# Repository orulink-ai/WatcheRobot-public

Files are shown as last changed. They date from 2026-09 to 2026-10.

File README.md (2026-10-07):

English | [简体中文](README_zh.md)

# WatcheRobot

The public WatcheRobot desktop-robot repository provides hardware files, mechanical models, the Python SDK, flashing tools, user guides, and Release asset documentation.

## Project Preview

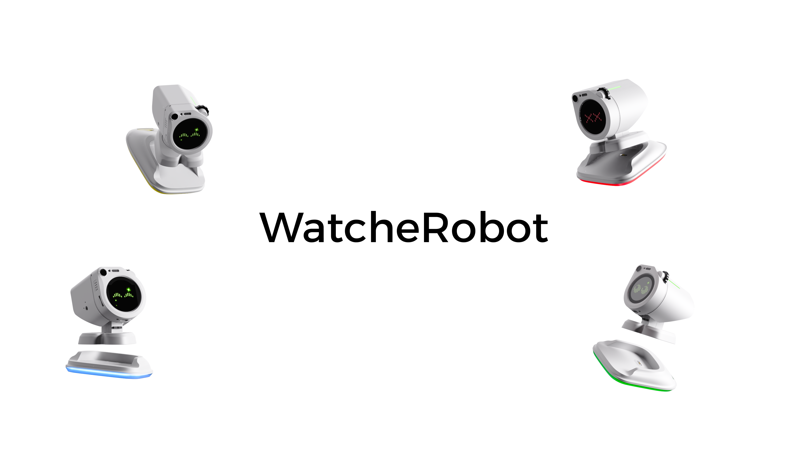
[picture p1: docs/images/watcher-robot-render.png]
WatcheRobot desktop robot


WatcheRobot is designed for desktop companionship, interactive demos, and developer experiments. It combines a Watcher head, ESP32-S3, an STM32 body board, servos, mechanical parts, and SD-card resources. You can use it through Desktop, the mobile App, or the Python SDK.

## Quick Start

### 1. Get the Repository

```bash
git clone --recurse-submodules https://github.com/orulink-ai/WatcheRobot-public.git
cd WatcheRobot-public
```

If `python-sdk/` is empty in an existing clone, run:

```bash
git submodule update --init --recursive
```

### 2. Prepare the Environment and Materials

See the [OSHW project](https://oshwhub.com/team_efhmhuqf/project_gbxcghnl) for the bill of materials and assembly steps.

| Prepare | Purpose |
| --- | --- |
| Assembled Watcher head and robot body | Flash and run the robot |
| ST-LINK V2 | Flash STM32 on the body board |
| USB data cable | Flash Himax and ESP32-S3 in the head |
| SD card and card reader | FAT32, 512-byte allocation unit; write expression, movement, and other resources |
| Conda | Create an isolated environment; the scripts prepare the remaining dependencies and tools |
| Computer or phone | Use Desktop, App, or SDK |

### 3. Prepare the Robot

Open the [Flashing Guide](docs/flashing.md) and follow its sections in order:

1. Flash STM32 on the body board.
2. Fully flash the Watcher head; the script writes Himax first and initializes ESP32-S3 from the release package.
3. Use a card reader and the repository writer to install the SD resources, then return the card to the head.
4. Power on, open Phone Control, connect the phone, then check one expression and one small movement.

### 4. Connect and Use

Download the required client or SDK from the [Latest Release](https://github.com/orulink-ai/WatcheRobot-public/releases/latest):

| Interface | Download |
| --- | --- |
| Windows Desktop | x64 `.exe` installer |
| macOS Desktop | Apple Silicon `.dmg` installer |
| Android App | `.apk` installer |
| iOS App | [TestFlight](https://testflight.apple.com/join/XFCFsm5M) |
| Python SDK | `watcherobot` `.whl`; follow the [SDK Guide](docs/sdk.md) |

See the [device network setup guide (Chinese PDF)](docs/manuals/device-network-setup.pdf). Once connected, run one expression and one movement to check the display, lights, and motion.

## Build Your Own Embedded Firmware (Development Preview, Not Publicly Released)

Alongside the [Python SDK](docs/sdk.md) for host applications, we are preparing
an independent ESP32-S3 hardware SDK. Developers own their `app_main`, UI, and
application logic, using a unified interface for body motion, lights, body touch,
camera, microphone, speaker, display, and screen touch. It does not require the
official application, Python SDK, Daemon, or server.

The first release targets three independently buildable examples: body, head,
and whole robot. STM32 and Himax use a validated firmware pairing; developers
are not expected to modify their firmware. See the
[Embedded Development Preview](docs/embedded-sdk.md) for scope and release gates.

Source and three examples are in [firmware/sdk/](firmware/sdk/README.md), currently
a development preview without full hardware acceptance or a pinned release.
Existing Releases and tools flash official firmware, not everyday custom builds.
Official application and STM32/Himax implementations remain outside SDK open-source scope.

## Repository Structure

```text
WatcheRobot-public/
├─ README.md / README_zh.md       English and Chinese project entry
├─ docs/
│  ├─ flashing.md / flashing_zh.md        Flashing guide
│  ├─ sd-card-assets.md / sd-card-assets_zh.md    SD-card resource guide
│  ├─ action-test.md / action-test_zh.md          First-run check
│  ├─ sdk.md / sdk_zh.md                  SDK guide
│  ├─ embedded-sdk.md / embedded-sdk_zh.md Embedded SDK preview and release boundaries
│  ├─ versions.md / versions_zh.md        Version sources
│  ├─ compatibility.md / compatibility_zh.md      Compatibility notes
│  ├─ release-process.md / release-process_zh.md  Release rules
│  ├─ governance.md / governance_zh.md            Repository rules
│  ├─ images/                              Documentation images
│  └─ manuals/                             PDF user manuals
├─ firmware/README.md / README_zh.md       Firmware download entry
├─ hardware/
│  ├─ pcb/
│  │  ├─ schematic/                        Schematics
│  │  ├─ layout/                           PCB layouts
│  │  ├─ gerber/                           Production files
│  │  ├─ bom/ / cpl/                      BOM and placement files
│  │  └─ pcb-source/                       EasyEDA Pro project source
│  └─ 3d-models/exports/                   STEP mechanical models
├─ python-sdk/                             Python SDK submodule
├─ skills/watche-release-flash/
│  ├─ SKILL.md                             English flashing Skill
│  └─ SKILL_zh.md                          Chinese flashing Skill
├─ skills/watche-sd-card-write/
│  ├─ SKILL.md                             English SD-card Skill
│  └─ SKILL_zh.md                          Chinese SD-card Skill
├─ tools/
│  ├─ flash.ps1                            Windows flashing entry
│  ├─ flash.sh                             macOS/Linux flashing entry
│  ├─ flash_setup.py                       Dependency setup and flashing dispatcher
│  ├─ install_sd_card_resources.py         SD validation and writer
│  └─ sd_package.py                        Official SD package resolver
├─ .github/                                Issue, PR, and CI configuration
├─ CONTRIBUTING.md / CONTRIBUTING_zh.md    Contribution guide
├─ SECURITY.md / SECURITY_zh.md            Security policy
└─ LICENSE                                 Open-source license
```

## Project Documentation

- [Flashing Guide](docs/flashing.md): environment, wiring, firmware flashing, SD card, and startup checks.
- [Firmware Entry Point](firmware/README.md): download package and flashing entry for each target.
- [SD-card Resources](docs/sd-card-assets.md) and [First-run Check](docs/action-test.md).
- [SDK Guide](docs/sdk.md): installation, pairing, and running Python scripts.
- [Embedded Development Preview](docs/embedded-sdk.md): hardware SDK goals, examples, and current release status.
- [Hardware Files](hardware/README.md): PCB and mechanical-file entry point.
- [Full User Manual (Chinese PDF)](docs/manuals/WatcheRobot-user-manual-20260724.pdf).
- [Version Sources](docs/versions.md), [Compatibility](docs/compatibility.md), [Release Rules](docs/release-process.md), and [Repository Rules](docs/governance.md).
- [Contributing Guide](CONTRIBUTING.md) and [Security Policy](SECURITY.md).

## Open-source Scope

- This repository publishes hardware production files, mechanical models, the Python SDK, flashing tools, and documentation.
- Python SDK source is provided through the `python-sdk/` submodule.
- ESP32-S3, Himax, STM32, App, server, and Desktop source code is not published here.
- Firmware, client installers, and SD-card resources are distributed through GitHub Releases.

## Technology Stack

| Area | Technology or format |
| --- | --- |
| Head | Watcher, Himax, ESP32-S3 |
| Body control | STM32F103, SWD / ST-LINK |
| SDK and flashing tools | Python, PowerShell, Bash |
| Hardware files | Schematic, PCB, BOM, CPL, Gerber, STEP |

## License

This repository uses [GPL-3.0](LICENSE). Subprojects and third-party components retain their own licenses.

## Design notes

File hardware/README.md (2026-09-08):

<p><strong>English</strong> | <a href="README_zh.md">简体中文</a></p>

# Hardware Package

This directory contains the public hardware reproduction materials for WatcheRobot.

For the public hardware project and material entry, see the [WatcheRobot OSHW project](https://oshwhub.com/team_efhmhuqf/project_gbxcghnl). Complete assembly and power-off wiring checks before firmware flashing.

## Package Map

| Board or asset | Schematic | Layout | Gerber | BOM | CPL | Source |
| --- | --- | --- | --- | --- | --- | --- |
| Feedback servo STM32 co-processor board | `pcb/schematic/SCH_STM32Servo_反馈舵机控制板.pdf` | `pcb/layout/PCB_STM32Servo_反馈舵机控制板.pdf` | `pcb/gerber/Gerber_STM32Servo_反馈舵机控制板/` | `pcb/bom/BOM_STM32Servo_反馈舵机控制板.xlsx` | `pcb/cpl/CPL_STM32Servo_反馈舵机控制板.xlsx` | `pcb/pcb-source/ProPrj_WatcheRobot2.0openSource_2026-06-17.epro` |
| Foot charging board | `pcb/schematic/SCH_FootCharger_脚底充电板.pdf` | `pcb/layout/PCB_FootCharger_脚底充电板.pdf` | `pcb/gerber/Gerber_FootCharger_脚底充电板/` | `pcb/bom/BOM_FootCharger_脚底充电板.xlsx` | `pcb/cpl/CPL_FootCharger_脚底充电板.xlsx` | `pcb/pcb-source/ProPrj_WatcheRobot2.0openSource_2026-06-17.epro` |
| Wireless charging base | `pcb/schematic/SCH_WirelessBase_无线充电底座.pdf` | `pcb/layout/PCB_WirelessBase_无线充电底座.pdf` | `pcb/gerber/Gerber_WirelessBase_无线充电底座/` | `pcb/bom/BOM_WirelessBase_无线充电底座.xlsx` | `pcb/cpl/CPL_WirelessBase_无线充电底座.xlsx` | `pcb/pcb-source/ProPrj_WatcheRobot2.0openSource_2026-06-17.epro` |
| Side LED board | `pcb/schematic/SCH_SideLight_侧边灯板.pdf` | `pcb/layout/PCB_SideLight_侧边灯板.pdf` | `pcb/gerber/Gerber_SideLight_侧边灯板/` | `pcb/bom/BOM_SideLight_侧边灯板.xlsx` | `pcb/cpl/CPL_SideLight_侧边灯板.xlsx` | `pcb/pcb-source/ProPrj_WatcheRobot2.0openSource_2026-06-17.epro` |
| Mechanical assembly | - | - | - | - | - | `3d-models/exports/WatcherRobot-mian.stp` |

## BOM Notes

The current BOM workbooks include:

- designator
- quantity
- parameter or model
- component description
- footprint
- manufacturer or brand
- manufacturer part number
- LCSC number
- supplier
- supplier part number
- datasheet
- mounting method
- alternate part

Purchase URLs and spare quantities are not fully populated in the current BOM files. Use `pcb/spares.md` to track spare parts and links.

## Large File Note

`3d-models/exports/WatcherRobot-mian.stp` is the current public mechanical assembly model. Future larger mechanical exports should be published through GitHub Releases or Git LFS rather than normal Git history.

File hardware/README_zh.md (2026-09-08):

<p><a href="README.md">English</a> | <strong>简体中文</strong></p>

# 硬件资料

物料和装配步骤见[立创开源硬件项目](https://oshwhub.com/team_efhmhuqf/project_gbxcghnl)。本目录保存 PCB、BOM、贴片坐标、Gerber 和机械模型。

| 实物 | 资料位置 |
| --- | --- |
| 身体主板，也就是反馈舵机 STM32 控制板 | `pcb/` 中名称包含 `STM32Servo` 的文件 |
| 脚底充电板 | `pcb/` 中名称包含 `FootCharger` 的文件 |
| 无线充电底座 | `pcb/` 中名称包含 `WirelessBase` 的文件 |
| 侧边灯板 | `pcb/` 中名称包含 `SideLight` 的文件 |
| 机械结构 | `3d-models/exports/WatcherRobot-mian.stp` |

先完成装配并断电检查接线，再开始烧录。身体主板使用 ST-LINK/SWD 烧录 STM32；上方 Watcher 头部通过 USB 烧录 Himax 和 ESP32-S3。

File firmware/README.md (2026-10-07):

English | [简体中文](README_zh.md)

# Firmware Entry Point

Independent ESP32 hardware SDK source and examples are provided in [sdk/](sdk/README.md) as a development preview. Official ESP32 application, Himax and STM32 implementations remain unpublished. Official flashable firmware is distributed through the [Latest Release](https://github.com/orulink-ai/WatcheRobot-public/releases/latest).

| Target | Download from the Release | Method |
| --- | --- | --- |
| STM32 body board | STM32 firmware package | Connect ST-LINK V2 to the body board and run the repository script |
| Watcher head | Paired Himax + ESP32-S3 package | Connect the head by USB and follow the guide for the initial full flash |
| SD card | SD resource archive | Install it with a card reader and the repository writer |

See the [Flashing Guide](../docs/flashing.md) for environment, wiring, and commands; [SD-card Resources](../docs/sd-card-assets.md) for card contents; and the [First-run Check](../docs/action-test.md) after startup.

Codex users can also ask the assistant to read [`skills/watche-release-flash/SKILL.md`](../skills/watche-release-flash/SKILL.md) and follow it for flashing.

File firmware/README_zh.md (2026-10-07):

[English](README.md) | 简体中文

# 固件入口

本仓库在 [sdk/](sdk/README_zh.md) 提供 ESP32 独立硬件 SDK 源码与示例（开发预览）。官方 ESP32 应用、Himax 和 STM32 固件实现仍不公开。官方可烧录固件由 [Latest Release](https://github.com/orulink-ai/WatcheRobot-public/releases/latest) 提供。

| 目标 | Release 中下载什么 | 使用方式 |
| --- | --- | --- |
| 身体主板 STM32 | STM32 固件包 | ST-LINK V2 连接身体主板，运行仓库烧录脚本 |
| Watcher 头部 | Himax + ESP32-S3 配套包 | USB 连接头部，首次安装按指南执行完整烧录 |
| SD 卡 | SD 资源压缩包 | 用读卡器和仓库写卡脚本安装 |

环境、接线和命令见[烧录指南](../docs/flashing_zh.md)，SD 卡内容见[SD 卡资源说明](../docs/sd-card-assets_zh.md)，开机后按[首次运行检查](../docs/action-test_zh.md)确认设备。

Codex 用户也可以让助手读取 [`skills/watche-release-flash/SKILL_zh.md`](../skills/watche-release-flash/SKILL_zh.md)，再按提示执行烧录。

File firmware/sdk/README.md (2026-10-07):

English | [简体中文](README_zh.md)

# ESP32 Embedded Hardware SDK (Development Preview)

This directory contains `watche_hw_*` source, required drivers and three independent
ESP-IDF projects. Developers own `app_main`, without the official app, Python SDK,
Daemon, server, SD card or models. Full hardware acceptance is pending; this is not
a stable release.

## Getting started

1. Download this repository or run `git clone https://github.com/orulink-ai/WatcheRobot-public.git`.
2. Install ESP-IDF **6.0.2** with ESP32-S3 tools and activate its terminal environment.
3. Edit `firmware/sdk/examples/robot/main/app_main.c`: this is your application.
4. From the repository root run `idf.py -C firmware/sdk/examples/robot build`.
5. Verify the port and paired firmware, back up required data, then run
   `idf.py -C firmware/sdk/examples/robot -p <PORT> flash monitor`.

Replace `<PORT>` with the actual serial port. Target: ESP32-S3, 16MB flash and
octal PSRAM for head examples. A successful build is not hardware safety evidence.
Long presses in body examples may trigger small movements; clear the mechanism first.

## Examples and modules

- `examples/body`: motion, lights, body touch. No motion without fresh valid position feedback.
- `examples/head`: LVGL and screen touch, JPEG capture, short PCM recording/playback.
- `examples/robot`: combined application; recommended starting point.
- `components/sdk/watche_hw_*`: public headers; other components are required dependencies.

Examples own their CMake, partitions and configuration. They never include the
official application project. Headers document parameters, ownership and threading.
Generic ACK/NACK are motion events only when matching the motion service's last
32 command sequences; older replies are ignored. Typed DONE/FAULT retain their
original sequence. Body init/close during event dispatch returns
`ESP_ERR_INVALID_STATE`; close only after dispatch returns.
Applications dispatch body callbacks with `dispatch_events`; submission is not motion
completion. Commands are rejected before readiness; reconnection never replays motion.
JPEG bytes are borrowed during callbacks; copy to retain. Blocking audio belongs in
application tasks. Lock LVGL access; never record or close display while holding its lock.

## Using a separate project

Keep a pinned checkout of this repository beside your project. In your top-level
CMake, set `HW_BODY` / `HW_HEAD` and include this SDKs `examples/sdk.cmake` before
`project()`, then call `watche_hw_check_idf()`. It finds components relative to itself,
not a private repository. Declare selected `watche_hw_*` main-component dependencies
and reuse the matching example manifest, partitions and sdkconfig.defaults.
Disable `HW_HEAD` for body-only projects. Do not ship products against floating main.

## Scripts and flashing

Windows: `./firmware/sdk/examples/hardware-sdk.ps1 robot build`.
macOS/Linux: `bash firmware/sdk/examples/hardware-sdk.sh robot build`.
Both accept example (default robot), action (default build), port. Actions are
build/flash/monitor; flash and monitor require an explicit port.

See the [official flashing guide](../../docs/flashing.md) for initial STM32/Himax
preparation and restoring official firmware. Official tools replace custom ESP32
applications; do not use them for everyday SDK flashing. Camera requires paired
PTL Himax firmware; current Releases are not guaranteed to contain it. Do not flash
unknown pairs before checking [acceptance](VALIDATION.md). First flash writes the
bootloader and partition table and may overwrite storage; do not erase flash.
Use `app-flash` for later application updates only after confirming unchanged partitions
on the connected device, not only in the local build. If the device's layout is
unknown or another firmware was installed, use this example's complete `flash`.

The body runtime probes a quiet peer using control-plane HELLO frames; no
periodic sensor stream or servo-position query is required for liveness. Five
seconds without a valid protocol event invalidates readiness and starts recovery.
Disconnect safety depends on STM32 mechanisms, not guaranteed ESP32 stop delivery.

## Licensing and maintenance

First-party source in this directory retains the upstream ESP32 [Apache-2.0](LICENSE)
license; the repository-root GPL-3.0 does not replace it. Seeed BSP, SSCMA, expander
and Espressif codec directories retain original licenses and copyright notices.
Registry dependencies keep their respective licenses. This is a public delivery
snapshot; the internal ESP32 repository remains the development source. Fixes must
flow back upstream, not create an independently maintained duplicate. Official
application and STM32/Himax implementations remain outside this publication scope.

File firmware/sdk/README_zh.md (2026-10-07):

[English](README.md) | 简体中文

# ESP32 嵌入式硬件 SDK（开发预览）

这里提供 `watche_hw_*` 源码、必要驱动和三个独立 ESP-IDF 工程。
开发者拥有自己的 `app_main`，不需要官方应用、Python SDK、Daemon、服务端、
SD 卡或模型。尚未完成全部实机验收，不是稳定版发布。

## 小白从这里开始

1. 下载本仓库，或执行 `git clone https://github.com/orulink-ai/WatcheRobot-public.git`。
2. 安装 ESP-IDF **6.0.2** 和 ESP32-S3 工具链，在 ESP-IDF 终端执行后续命令。
3. 打开 `firmware/sdk/examples/robot/main/app_main.c`，这是你自己的应用。
4. 在仓库根目录执行 `idf.py -C firmware/sdk/examples/robot build`。
5. 确认设备端口和配套固件，备份需要的数据，再执行
   `idf.py -C firmware/sdk/examples/robot -p <PORT> flash monitor`。

`<PORT>` 替换为实际串口名称，不要原样输入。工程目标为 ESP32-S3、16MB Flash，
头部示例启用 octal PSRAM。构建不等于实机安全验收。身体示例长按可能触发小幅运动，
首次操作前保持机构运动空间畅通。

## 示例与模块

- `examples/body`：运动、灯光、身体触摸。未收到新鲜有效位置反馈不运动。
- `examples/head`：LVGL 页面和屏幕触摸、JPEG 拍照、短时 PCM 录放音。
- `examples/robot`：上述能力组合，建议作为开发起点。
- `components/sdk/watche_hw_*`：公共接口；`components` 其余目录是必要底层依赖。

全部示例有自己的 CMake、分区和配置，不引入官方固件顶层工程。
公共头文件说明参数、所有权和线程限制。身体回调由应用调用 `dispatch_events`
分发，运动提交成功不是运动完成；未就绪拒绝控制，重连不重放动作。
通用 ACK/NACK 仅在匹配运动服务最近 32 个命令时报告为运动事件，超出窗口的
迟到回复忽略；带类型的完成/故障保留原始序列。事件分发期间 init/close 返回
`ESP_ERR_INVALID_STATE`，应用应在分发返回后再关闭。
身体运行层在通信安静时发送 HELLO 存活探测，不要求 STM32 周期上报传感器，
也不查询舵机位置。超过 5 秒未收到有效协议事件会退出就绪并重新握手。
摄像头回调 JPEG 只在回调内有效，需保存则复制；音频阻塞操作放应用任务；
LVGL 操作使用显示锁，不能在持锁时录音或关闭显示。

## 在自己的新工程中使用

将本仓库的固定版本作为依赖保留在项目旁边。自己的顶层 CMake 在
`project()` 前设置 `HW_BODY` / `HW_HEAD`，并 include 本 SDK 的
`examples/sdk.cmake`；它使用自己的位置寻找组件，不依赖私有仓库。
在 `project()` 后调用 `watche_hw_check_idf()`。主组件声明实际使用的
`watche_hw_*` 依赖，并沿用相应示例的依赖清单、分区和 sdkconfig.defaults。
只需身体时关闭 `HW_HEAD`，不会初始化头部。不要依赖浮动 main 发布产品。

## 脚本与烧录边界

Windows：`./firmware/sdk/examples/hardware-sdk.ps1 robot build`。
macOS/Linux：`bash firmware/sdk/examples/hardware-sdk.sh robot build`。
两个入口的参数都是：示例（默认 robot）、操作（默认 build）、端口。
操作支持 build/flash/monitor；flash 和 monitor 必须显式指定端口。

首次准备 STM32/Himax 和恢复官方整机见[官方烧录指南](../../docs/flashing_zh.md)。
现有官方工具会替换自定义 ESP32 应用，不要用于日常 SDK 烧录。
SDK 摄像头需要 PTL 配对 Himax；现有 Release 不保证包含该配对，
未经[兼容验收](VALIDATION.md)确认不要直接刷写未知镜像。
自定义首次 flash 会写 bootloader 和分区表，可能覆盖存储；不要执行 erase-flash。
确认连接设备上的分区不变后日常可用 `app-flash`，不能只检查本地构建配置。
设备布局未知或曾安装另一份固件时，使用本示例的完整 `flash`。
断线停止依赖 STM32 安全机制，
不能承诺断线后 ESP32 还能发送停止命令。

## 许可证与维护

本目录自有代码沿用内部 ESP32 源码的 [Apache-2.0](LICENSE)，
不以公开仓库根目录 GPL-3.0 替代原许可。Seeed BSP、SSCMA、I/O expander
和 Espressif codec 等保留各目录原有许可证与版权；注册表依赖也适用其各自许可。
本目录是 SDK 的对外交付快照，开发源仍在内部 ESP32 仓库；对外修复应回流开发源，
不能维护两套独立实现。官方应用、STM32/Himax 实现不在本目录公开范围内。

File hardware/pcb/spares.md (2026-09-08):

<p><strong>English</strong> | <a href="spares_zh.md">简体中文</a></p>

# Event Spare Parts

Use this file to track spare parts prepared for reproduction or maintenance. The BOM workbooks contain model, supplier, supplier part number, and alternate-part fields; this document records what is physically available on site.

## Spare Parts Template

| Board | Part or designator | Recommended spare qty | Supplier link | Alternate part | Event location | Notes |
| --- | --- | ---: | --- | --- | --- | --- |
| Feedback servo STM32 co-processor board | TBD | TBD | TBD | TBD | TBD | Fill before release. |
| Foot charging board | TBD | TBD | TBD | TBD | TBD | Fill before release. |
| Wireless charging base | TBD | TBD | TBD | TBD | TBD | Fill before release. |
| Side LED board | TBD | TBD | TBD | TBD | TBD | Fill before release. |

## Minimum Event Checklist

- Confirm every spare item maps to a BOM row.
- Add a purchase or supplier link where possible.
- Mark spare parts that are prepared but not normally assembled.
- Keep the physical storage location clear enough for builders and maintainers.
- Update this file before publishing a full hardware release.

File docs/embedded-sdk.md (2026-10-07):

English | [简体中文](embedded-sdk_zh.md)

# Independent Embedded Hardware SDK: Development Preview

## Current Status

This document describes direction and interface boundaries. Development-preview
source, independent examples and build instructions are in
[firmware/sdk](../firmware/sdk/README.md). There is no stable release or complete
hardware-validated STM32/Himax pairing yet; do not treat the preview as stable.

The available development entry remains the [Python SDK](sdk.md). Existing
firmware and client assets are listed in
[Releases](https://github.com/orulink-ai/WatcheRobot-public/releases).

## Two Development Paths

| Path | Runs on | Developer ownership | Status |
| --- | --- | --- | --- |
| Python SDK | Host computer | Applications using existing device firmware | Public entry available; see the SDK guide |
| Embedded hardware SDK | ESP32-S3 | Own app_main, UI, interactions, and hardware calls | Development preview; not publicly released |

The embedded SDK aims to run independently of the official application, without
the Python SDK, Daemon, or server. It does not change the existing
Python SDK/Daemon/Application architecture.

## First-release Target Capabilities

| Module | Target interfaces |
| --- | --- |
| Body motion | Target angles in degrees, duration, stop; completion, rejection, and fault events |
| Body lights | Zone colors, brightness, and basic effects |
| Body touch | Ordered press, release, and long-press events |
| Camera | PTL backend; single capture, continuous JPEG frames, stop, and status |
| Microphone and speaker | PCM capture, playback, volume, and format configuration |
| Display and screen touch | Standard LCD/LVGL/touch handles and access protection |

Modules are optional components named `watche_hw_*`; developers own application
behavior. Voice assistants, cloud connections, official expressions, AI inference,
and model management are outside the first release. The target toolchain is
ESP-IDF **6.0.2** and ESP32-S3, with required dependencies pinned.

The runtime owns MCU handshaking, event collection, state transitions, and disconnect
handling. Applications subscribe to events. Successful motion submission does not
mean completion; commands must be rejected before readiness, and reconnects must
not replay old motion. Callbacks handle lightweight events; expensive work belongs
in application tasks. Published SDK documentation must specify resource contracts,
including JPEG buffer lifetime and display locking.

## Independent Example Targets

- Body: touch changes lights, user-triggered small motion, completion/fault logging.
- Head: simple LVGL page, screen touch, JPEG capture, short PCM recording/playback.
- Whole robot: combine these capabilities and demonstrate resource ownership.

Basic examples require neither an SD card nor model resources. Developers edit
example application code without starting the official top-level firmware project
or modifying STM32/Himax firmware.

## Flashing and Safety Boundaries

The final delivery must distinguish first-time STM32/Himax preparation, everyday
custom ESP32 flashing, and restoration of official whole-robot firmware.

The current [Flashing Guide](flashing.md) covers official firmware. Existing tools
may write the official ESP32 application and must not be used to preserve a custom
application. Custom partition layouts may overwrite storage; the released guide
must document backup and restoration. Until the independent development entry is
released, this preview provides no unverified custom flashing commands.

After disconnection, ESP32 cannot guarantee delivery of a stop command; safety
depends on STM32-side mechanisms. Motion examples require limit, small-movement,
and stop validation. A successful build is not evidence of motion safety.

## Public Release Gates

- Confirm public source delivery, licensing, and a fixed Git revision; update
  the published open-source scope accordingly.
- Validate installation, all three builds, and application-only edits from a clean checkout.
- Run Windows/Linux host tests and pinned-IDF CI, including official firmware regression.
- Validate motion, lights, all three body-touch events, JPEG decoding, PCM recording/
  playback, screen touch, and combined operation on hardware. Missing or incompatible
  modules must not hang the device or unintentionally drive motors.
- Record SDK/STM32 versions, Himax image checksum, board revision, and acceptance evidence.
- Validate custom flashing and official restoration, with equivalent PowerShell/Shell entries.

Do not release version one until both head and body pass acceptance. This document
does not promise a release date.

[Back to the project](../README.md)

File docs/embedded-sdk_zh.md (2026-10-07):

[English](embedded-sdk.md) | 简体中文

# 独立嵌入式硬件 SDK：开发预览

## 当前状态

这是一份开发方向和接口边界说明。开发预览源码、独立示例及构建入口见
[firmware/sdk](../firmware/sdk/README_zh.md)。尚无稳定发布版本和完整实机
STM32/Himax 配对验收；请勿将预览当作稳定版。

目前可用的开发入口仍是 [Python SDK](sdk_zh.md)。固件和客户端的已有发行
资产见 [Release](https://github.com/orulink-ai/WatcheRobot-public/releases)。

## 两种开发方式

| 方式 | 运行位置 | 开发者控制的内容 | 状态 |
| --- | --- | --- | --- |
| Python SDK | 电脑端 | 基于已有设备固件编写应用 | 已有公开入口，见 SDK 指南 |
| 嵌入式硬件 SDK | ESP32-S3 | 自己的 app_main、UI、交互及硬件调用 | 源码开发预览，尚未正式发布 |

嵌入式 SDK 的目标是脱离官方应用运行，不要求 Python SDK、Daemon 或服务端。
它不改变现有 Python SDK/Daemon/Application 架构。

## 首版目标能力

| 模块 | 目标接口 |
| --- | --- |
| 身体运动 | 目标角度（度）、运动时间、停止；完成、拒绝、故障事件 |
| 身体灯光 | 分区颜色、亮度和基础灯效 |
| 身体触摸 | 按下、释放、长按的有序事件流 |
| 摄像头 | PTL 后端，单次拍照、连续 JPEG 取帧、停止与状态 |
| 麦克风与扬声器 | PCM 采集、播放、音量与格式配置 |
| 屏幕与屏幕触摸 | 标准 LCD/LVGL/触摸句柄及访问保护 |

组件按模块可选，统一使用 `watche_hw_*` 命名；开发者编写自己的业务。
首版不包含语音助手、云连接、官方表情系统、AI 推理和模型管理。
目标工具链为 ESP-IDF **6.0.2**、ESP32-S3，必要依赖固定版本。

运行层负责 MCU 握手、事件采集、状态转换和断线处理；应用通过订阅接收
事件。运动提交成功不等于运动完成，未就绪应拒绝控制，重连不重放旧运动。
回调只处理轻量事件，耗时业务放到应用任务；JPEG 缓冲生命周期和显示锁
等资源合同必须在正式 SDK 文档中明确。

## 独立示例目标

- 身体：触摸改变灯光，用户触发小幅运动，打印完成或故障事件。
- 头部：简单 LVGL 页面、屏幕触摸、JPEG 拍照、短时 PCM 录音与回放。
- 整机：组合上述能力，展示模块共同运行和资源所有权。

基础示例不依赖 SD 卡或模型资源。开发者只修改示例应用代码，不必启动
官方固件顶层工程，也不要求修改 STM32/Himax 固件。

## 烧录与安全边界

正式交付必须分别说明首次准备 STM32/Himax、日常只烧录自定义 ESP32、
恢复官方整机固件三个流程。

当前 [烧录指南](flashing_zh.md)描述的是官方整机流程；现有工具可能写入
官方 ESP32 应用，不能用于保留自定义应用。自定义工程也可能改变分区并
覆盖存储。预览的构建与自定义烧录入口见 [SDK 入门说明](../firmware/sdk/README_zh.md)，
操作前请阅读其中的备份要求和配对固件限制；稳定版仍需完整实机验收。

断线后不能保证 ESP32 仍能发送停止命令，安全停止依赖 STM32 侧机制。
运动示例必须经过限位、小幅运动和停止验收，不能把构建通过当作安全证明。

## 公开发布门禁

- 确认公开源码交付方式、许可证和固定 Git 版本；同步仓库开源范围说明。
- 从干净 checkout 验证工具安装、三个示例构建及仅修改应用代码的流程。
- Windows/Linux 主机测试和固定 IDF CI；回归官方固件。
- 实机验收运动、灯光、三类身体触摸、JPEG 解码、PCM 录放音、屏幕触摸
  和整机组合；缺失或不兼容模块不得挂死或无意驱动电机。
- 记录 SDK 版本、STM32 版本、Himax 镜像校验值、板卡版本和验收证据。
- 验证自定义烧录与官方恢复流程，并提供语义一致的 PowerShell/Shell 入口。

头部和身体全部通过前不发布首版；本文不承诺发布日期。

[返回项目入口](../README_zh.md)

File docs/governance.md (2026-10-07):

<p><strong>English</strong> | <a href="governance_zh.md">简体中文</a></p>

# Governance

`orulink-ai/WatcheRobot-public` is the public repository for hardware materials, mechanical models, SDK source, user documentation, flashing tools, and release coordination.

Maintainers should keep the following boundaries clear:

- Python SDK source is provided through the `python-sdk/` submodule.
- Hardware source changes belong under `hardware/pcb/`, `hardware/3d-models/`, or `hardware/assembly/`.
- `firmware/sdk/` publishes the independent ESP32 hardware SDK, required drivers and examples, retaining Apache-2.0 and original third-party licenses.
- Official ESP32 application, STM32F103 and Himax implementations are not published in this repository.
- App, server, desktop, firmware, and SD-card runtime artifacts are release assets only.
- Release artifacts are uploaded to GitHub Releases, not committed to Git.
- Private implementation details do not belong in public docs.

Branch protection should require CI and owner review before public release.

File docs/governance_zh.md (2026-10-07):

<p><a href="governance.md">English</a> | <strong>简体中文</strong></p>

# 仓库规则

- Python SDK 使用 `python-sdk/` 子模块。
- 硬件资料放在 `hardware/`。
- `firmware/sdk/` 公开独立 ESP32 硬件 SDK、必要驱动和示例；保留该目录 Apache-2.0 与第三方原有许可证。
- 官方 ESP32 应用、STM32F103、Himax、App、服务端和桌面端实现不放入本仓库。
- 固件、客户端安装包和 SD 卡资源只上传到 GitHub Releases。
- 私有路径、账号、凭据和内部日志不得写入公开文档。

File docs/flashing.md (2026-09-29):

English | [简体中文](flashing_zh.md)

# Flashing and First Use

See the [OSHW project](https://oshwhub.com/team_efhmhuqf/project_gbxcghnl) for parts and assembly. Once hardware is ready, follow the steps below.

## 1. Prepare Materials, Files, and Environment

Have the STM32 body board, Watcher head, ST-LINK V2, USB data cable, SD card, and card reader ready. Disconnect power before changing wiring or inserting/removing the SD card.

Download and extract these assets from the [Latest Release](https://github.com/orulink-ai/WatcheRobot-public/releases/latest):

| Asset name contains | Purpose |
| --- | --- |
| STM32 | Body board firmware |
| PTL-paired | Complete head Himax and ESP32-S3 firmware and paired tools |
| sd-resources | SD-card resources; the writer can also download the latest package |

Use Conda, or install [Miniconda](https://docs.conda.io/projects/miniconda/en/latest/) first. Open a Conda-enabled terminal at the repository root (Anaconda PowerShell Prompt on Windows). Create the dedicated environment once:

```sh
conda create -n watcherobot python=3.12 pip -y
conda activate watcherobot
```

Run the following commands at the repository root, replacing firmware paths with the extracted folders. The script prepares dependencies and flashing tools; initial setup requires internet access.

## 2. Flash the STM32 Body Board

Connect ST-LINK V2 to the four-pin connector on the board inside the body. Follow the labels, not wire colors.

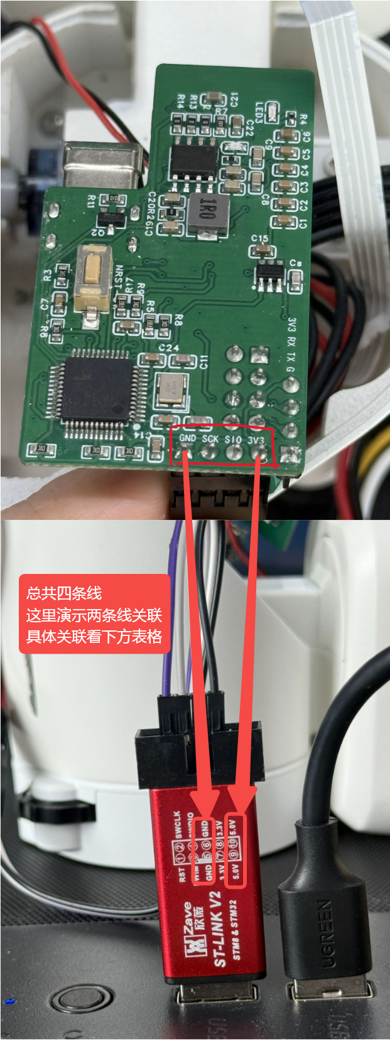
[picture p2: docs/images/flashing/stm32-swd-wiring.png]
STM32 body board to ST-LINK V2 wiring


| Body board | ST-LINK V2 |
| --- | --- |
| SIO | SWDIO |
| SCK | SWCLK |
| GND | GND |
| 3V3 | 3.3V, subject to the actual power arrangement |

Never connect 5V to 3V3. Do not parallel the ST-LINK 3.3V power output with an externally powered board. Check wiring and power, then connect ST-LINK to the computer.

Windows:

```powershell
powershell -NoProfile -ExecutionPolicy Bypass -File tools/flash.ps1 stm32 --package "extracted-STM32-folder"
```

macOS/Linux:

```sh
bash tools/flash.sh stm32 --package "extracted-STM32-folder"
```

Wait for `Programming Finished`, `Verified OK`, and `Resetting Target` with successful completion. Disconnect power and remove ST-LINK before continuing. If the chip cannot be reached, disconnect power and check wiring at both ends.

## 3. Flash Head Himax and ESP32-S3

Connect the Watcher head with a USB data cable. First run this command to install dependencies and list ports; it does not write firmware:

Windows:

```powershell
powershell -NoProfile -ExecutionPolicy Bypass -File tools/flash.ps1 head --package "extracted-PTL-paired-folder"
```

macOS/Linux:

```sh
bash tools/flash.sh head --package "extracted-PTL-paired-folder"
```

Identify the ports corresponding to SERIAL-B and SERIAL-A in the output. On Windows, the `desc:` names map to these arguments; COM61 and COM62 are examples:

| Device name | Port (example) | Command argument |
| --- | --- | --- |
| USB-Enhanced-SERIAL-B CH342 (ESP32) | COM61 | `--port COM61` |
| USB-Enhanced-SERIAL-A CH342 (Himax) | COM62 | `--vision-port COM62` |

You can also run a read-only query; neither command writes firmware:

```powershell
# Windows
Get-PnpDevice -PresentOnly -Class Ports | Where-Object { $_.FriendlyName -match 'SERIAL-[AB].*CH342' } | Select-Object FriendlyName
```

```sh
# Windows/macOS/Linux, after the tool-preparation command above
python -m serial.tools.list_ports -v
```

Alternatively, open Windows Device Manager → Ports (COM & LPT) and read the COM number in parentheses after each name. Connect only one Watcher for flashing.

The script prints a concise Device name / Port / Command argument table. Use SERIAL-B for `--port` and SERIAL-A for `--vision-port`. Replace both port numbers below with the reported values for the initial full flash:

```powershell
powershell -NoProfile -ExecutionPolicy Bypass -File tools/flash.ps1 head --package "extracted-PTL-paired-folder" --port COM61 --vision-port COM62 --factory
```

Full macOS/Linux flashing command:

```sh
bash tools/flash.sh head --package "extracted-PTL-paired-folder" --port "/dev/SERIAL_B" --vision-port "/dev/SERIAL_A" --factory
```

`/dev/SERIAL_B` and `/dev/SERIAL_A` are placeholders. Replace them with the identified ESP32 and Himax serial paths respectively; do not infer the mapping from port number order. Do not flash until the mapping is confirmed.

Use `--factory` for the initial installation of this complete head package so the ESP32 partition table, application, and storage all come from the same release. It overwrites existing ESP32 data and is not the data-preserving update path.

One command automatically checks the package and ports, flashes ESP32-S3, starts it and confirms Himax power initialization, flashes Himax, then restarts. No intermediate confirmation or separate flashing command is needed. After `HX flash completed; reboot accepted.`, wait for `PTL paired flash completed.` and `Head flash completed successfully` to confirm writing and restart commands completed. Keep the cable connected. Failures identify the stage; check normal operation in step 5.

Stop if ports are missing or inaccessible: automatic CH342 driver installation and Linux serial permission setup are not yet supported.

## 4. Prepare the SD Card with a Card Reader

Follow the [SD-card Resources guide](sd-card-assets.md) to prepare the format and write resources. Return the card to the head, then continue to the power-on step below.

## 5. Power On and Use

Check the SD card and wiring, connect power, and press the power button. Wait for the normal screen, then open Phone Control. If it opens and the phone connects over BLE, the ESP32, STM32 link, and head control path are working. Allow a few seconds on first entry for BLE and body-control initialization.

Download Desktop or Android installers from the Release; use its TestFlight link for iOS. Python users can follow the [SDK Guide](sdk.md).

After connecting, follow the [First-run Check](action-test.md) with an expression, a light effect, and a movement within a safe range.

## Use the Skill (Optional)

Open this repository in an AI coding assistant and ask:

> Read skills/watche-release-flash/SKILL.md, use the dedicated Conda environment, confirm the firmware folder and connected target, then flash and report the actual result.

Without an AI assistant, simply use the commands above.

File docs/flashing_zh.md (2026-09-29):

[English](flashing.md) | 简体中文

# 烧录与首次使用

材料清单和组装方法见[立创项目](https://oshwhub.com/team_efhmhuqf/project_gbxcghnl)。准备好硬件后，按以下步骤操作。

## 1. 准备材料、文件和环境

准备身体 STM32 主板、Watcher 头部、ST-LINK V2、USB 数据线、SD 卡和读卡器。接线、插拔 SD 卡前先断电。

从 [Latest Release](https://github.com/orulink-ai/WatcheRobot-public/releases/latest) 下载并解压：

| 附件名称包含 | 用途 |
| --- | --- |
| STM32 | 身体主板固件 |
| PTL-paired | 头部 Himax 和 ESP32-S3 完整固件及配套工具 |
| sd-resources | SD 卡表情、动作等资源；脚本也可自动下载最新包 |

使用已安装的 Conda；没有时先安装 [Miniconda](https://docs.conda.io/projects/miniconda/en/latest/)。在仓库根目录打开支持 Conda 的终端（Windows 可用 Anaconda PowerShell Prompt），只需创建一次专用环境：

```sh
conda create -n watcherobot python=3.12 pip -y
conda activate watcherobot
```

在仓库根目录运行以下命令，将固件路径替换为实际解压目录。依赖和烧录工具由脚本自动准备，首次运行需联网。

## 2. 烧录身体主板 STM32

用 ST-LINK V2 连接身体内部主板的四针接口，按印字对应，不按线色猜。

STM32 身体主板与 ST-LINK V2 接线

| 身体主板 | ST-LINK V2 |
| --- | --- |
| SIO | SWDIO |
| SCK | SWCLK |
| GND | GND |
| 3V3 | 3.3V，按实际供电方式确认 |

不要将 5V 接入 3V3；主板外部供电时，不要并接 ST-LINK 的 3.3V 电源输出。检查接线和供电后，将 ST-LINK 插入电脑。

Windows：

```powershell
powershell -NoProfile -ExecutionPolicy Bypass -File tools/flash.ps1 stm32 --package "解压后的STM32目录"
```

macOS/Linux：

```sh
bash tools/flash.sh stm32 --package "解压后的STM32目录"
```

依次看到 `Programming Finished`、`Verified OK`、`Resetting Target` 且成功结束后，断电移除 ST-LINK，再继续下一步。若连不上芯片，先断电核对两端接线。

## 3. 烧录头部 Himax 和 ESP32-S3

用 USB 数据线连接 Watcher 头部。先运行以下命令，脚本安装依赖并列出串口；此命令不写入固件：

Windows：

```powershell
powershell -NoProfile -ExecutionPolicy Bypass -File tools/flash.ps1 head --package "解压后的PTL-paired目录"
```

macOS/Linux：

```sh
bash tools/flash.sh head --package "解压后的PTL-paired目录"
```

在上一步输出中确认 SERIAL-B 和 SERIAL-A 对应的端口。Windows 的 `desc:` 名称与参数对应如下，以 COM61、COM62 为例：

| 设备名称 | 端口（示例） | 命令参数 |
| --- | --- | --- |
| USB-Enhanced-SERIAL-B CH342（ESP32） | COM61 | `--port COM61` |
| USB-Enhanced-SERIAL-A CH342（Himax） | COM62 | `--vision-port COM62` |

也可单独运行只读查询命令，不会写入固件：

```powershell
# Windows
Get-PnpDevice -PresentOnly -Class Ports | Where-Object { $_.FriendlyName -match 'SERIAL-[AB].*CH342' } | Select-Object FriendlyName
```

```sh
# 已完成上面的工具准备后，Windows/macOS/Linux 均可运行
python -m serial.tools.list_ports -v
```

Windows 还可在「设备管理器 → 端口（COM 和 LPT）」查看名称后括号中的 COM 号。只连接一台待烧录的 Watcher。

脚本会直接打印“设备名称 / 端口 / 命令参数”表。`--port` 填 SERIAL-B，`--vision-port` 填 SERIAL-A。将下面两处端口号替换为表中实际值后运行首次完整烧录：

```powershell
powershell -NoProfile -ExecutionPolicy Bypass -File tools/flash.ps1 head --package "解压后的PTL-paired目录" --port COM61 --vision-port COM62 --factory
```

macOS/Linux 完整烧录命令：

```sh
bash tools/flash.sh head --package "解压后的PTL-paired目录" --port "/dev/SERIAL_B" --vision-port "/dev/SERIAL_A" --factory
```

`/dev/SERIAL_B` 和 `/dev/SERIAL_A` 是占位路径，分别替换成查询到的 ESP32 和 Himax 串口路径；不要按端口数字大小判断。无法确认对应关系时，先不要烧录。

`--factory` 用于首次安装这套完整头部固件，确保 ESP32 分区表、应用和存储区来自同一发布包。它会覆盖 ESP32 中原有数据，不用于保留数据的日常升级。

一条命令自动完成：检查 → 烧录 ESP32-S3 → 启动并确认 Himax 供电初始化 → 烧录 Himax → 重启。无需中途输入确认或另行烧录。看到 `HX flash completed; reboot accepted.` 后继续等待，直到 `PTL paired flash completed.` 和 `Head flash completed successfully` 表示写入及重启指令完成，期间不要拔线。若失败，按日志标明的阶段排查；正常运行按第 5 步检查。

若串口未出现或无法访问，先停止：当前脚本尚不能自动处理 CH342 驱动和 Linux 串口权限。

## 4. 用读卡器准备 SD 卡

按 [SD 卡资源指南](sd-card-assets_zh.md)完成格式设置和资源写入，将卡插回头部后，继续下一步上电。

## 5. 上电并使用

确认 SD 卡和接线就位，接通电源并按电源键开机。等待正常界面出现，再打开 Phone Control；页面能进入且手机能通过 BLE 连接，说明 ESP32、STM32 通信和头部控制链路已工作。首次进入时等待几秒完成 BLE 和身体控制初始化。

从 Release 下载 Desktop 或 Android 安装包；iOS 使用页面中的 TestFlight。Python 用户见 [SDK 指南](sdk_zh.md)。

连接后按[首次运行检查](action-test_zh.md)尝试一个表情、灯效和安全范围内的动作。

## 使用 Skill（可选）

用 AI 编程助手打开本仓库，告诉它：

> 读取 skills/watche-release-flash/SKILL_zh.md，使用已创建的专用 Conda 环境，确认固件目录和连接设备后执行烧录，报告真实结果。

不使用 AI 助手时，按上面的命令操作即可。

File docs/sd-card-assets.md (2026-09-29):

English | [简体中文](sd-card-assets_zh.md)

# SD-card Resources

For script setup, see [Prepare Materials, Files, and Environment](flashing.md#1-prepare-materials-files-and-environment).

## 1. Prepare the SD card

Power off the robot, remove the SD card, and connect it through a card reader. Use **FAT32 with a 512-byte allocation unit**. A card already using these settings does not need reformatting.

On Windows, right-click the SD card in **This PC → Format**, select **FAT32** and **512 bytes**, then click **Start**. **Formatting deletes all files on the card, including existing resources and creator works. Back them up first.**

Alternatively, activate the dedicated Conda environment in an Administrator PowerShell terminal and run this formatter from the repository root. Replace `E:\` with the actual SD card:

```powershell
powershell -NoProfile -ExecutionPolicy Bypass -File tools/flash.ps1 sd-format --drive "E:\"
```

The command formats immediately without an additional confirmation prompt; check the drive letter and back up files before running it. The formatter supports Windows removable drives only and verifies FAT32 and the 512-byte allocation unit afterward. It stops with an error if Windows cannot format the selected capacity with these settings.

## 2. Write resources

Activate the dedicated Conda environment and run from the repository root. Replace the drive or mount path below with the actual card. Without `--package`, the writer downloads the latest official resources:

```powershell
# Windows: download the latest official resources
powershell -NoProfile -ExecutionPolicy Bypass -File tools/flash.ps1 sd --drive "E:\"
```

```sh
# macOS/Linux: download the latest official resources
bash tools/flash.sh sd --drive "/Volumes/WATCHE"
```

If `watche-sd-resources-*.tar.gz` was downloaded from the Release, append `--package "archive path"` to the matching command. The writer verifies the archive and preserves existing works.

The final `Installed ... successfully` message confirms writing and verification. Eject the card safely, return it to the powered-off head, then follow [step 5 of the flashing guide](flashing.md#5-power-on-and-use) to start and check the robot.

## Installed layout

The writer converts the archive into this device layout; no manual extraction is needed:

```text
SD-card root/
└─ watche/
   ├─ assets/
   │  ├─ actions/                 Action objects
   │  ├─ anim/                    Expression animation objects
   │  └─ sfx/                     Sound objects
   ├─ official/current/
   │  ├─ official_catalog.json    Official resource catalog
   │  ├─ fixed_states.json        Fixed-state mapping
   │  └─ resource_manifest.json   Resource integrity manifest
   ├─ works/
   │  └─ works_catalog.json       Creator-work catalog
   ├─ system/
   │  ├─ layout.json              Layout marker
   │  └─ accepted_official.json   Installed official-resource record
   └─ staging/                    Installation transaction workspace
```

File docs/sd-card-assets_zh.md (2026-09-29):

[English](sd-card-assets.md) | 简体中文

# SD 卡资源

运行脚本所需环境见[准备材料、文件和环境](flashing_zh.md#1-准备材料文件和环境)。

## 1. 准备 SD 卡

断电取出 SD 卡，通过读卡器连接电脑，使用 **FAT32，分配单元大小 512 字节**。已符合要求的卡无需重新格式化。

Windows 可在「此电脑」中右键 SD 卡 →「格式化」，选择「FAT32」和「512 字节」，点击「开始」。**格式化会删除卡内全部文件，包括原有资源和用户作品，请先备份。**

也可以在管理员 PowerShell 中激活专用 Conda 环境，从仓库根目录运行格式化脚本（将 `E:\` 换成实际 SD 卡）：

```powershell
powershell -NoProfile -ExecutionPolicy Bypass -File tools/flash.ps1 sd-format --drive "E:\"
```

命令执行后直接格式化，不再二次确认；运行前请核对盘符并备份文件。脚本仅支持 Windows 可移动盘，完成后检查 FAT32 和 512 字节分配单元；若系统不支持该容量与格式组合，会报错停止。

## 2. 写入资源

在已激活的专用 Conda 环境中从仓库根目录运行，以下盘符或挂载路径换成实际 SD 卡。未指定 `--package` 时自动下载最新官方资源：

```powershell
# Windows：自动下载最新官方资源
powershell -NoProfile -ExecutionPolicy Bypass -File tools/flash.ps1 sd --drive "E:\"
```

```sh
# macOS/Linux：自动下载最新官方资源
bash tools/flash.sh sd --drive "/Volumes/WATCHE"
```

若已下载 Release 中的 `watche-sd-resources-*.tar.gz`，在相应命令末尾添加 `--package "压缩包路径"`。脚本会校验压缩包并保留已有作品。

日志最后出现 `Installed ... successfully` 表示写入和校验完成。安全弹出卡，在机器人断电状态下插回头部，再按[烧录指南第 5 步](flashing_zh.md#5-上电并使用)开机检查。

## 写入后的目录

脚本将资源包转换为以下设备目录，无需手动解压：

```text
SD 卡根目录/
└─ watche/
   ├─ assets/
   │  ├─ actions/                 动作资源对象
   │  ├─ anim/                    表情动画对象
   │  └─ sfx/                     音效对象
   ├─ official/current/
   │  ├─ official_catalog.json    官方资源目录
   │  ├─ fixed_states.json        固定状态映射
   │  └─ resource_manifest.json   资源完整性清单
   ├─ works/
   │  └─ works_catalog.json       用户作品目录
   ├─ system/
   │  ├─ layout.json              SD 布局标识
   │  └─ accepted_official.json   已安装官方资源记录
   └─ staging/                    安装事务临时目录
```

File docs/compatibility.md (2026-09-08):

English | [简体中文](compatibility_zh.md)

# Compatibility

Each Release note lists the corresponding STM32, Himax, ESP32-S3, SD-card, client, and SDK versions. Use that table when selecting downloads, and check the current Release notes again when upgrading any component.

Release notes should use this table:

| STM32 | Himax | ESP32-S3 | SD card | Desktop | App | SDK |
| --- | --- | --- | --- | --- | --- | --- |
| See Release | See Release | See Release | See Release | See Release | See Release | See Release |

See the [Flashing Guide](flashing.md) for the flashing and card-writing sequence.

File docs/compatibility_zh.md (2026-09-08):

[English](compatibility.md) | 简体中文

# 配套关系

每个 Release 的说明会列出 STM32、Himax、ESP32-S3、SD 卡、客户端和 SDK 的对应版本。下载时按该表选择需要的文件；升级其中一项时，重新查看当前 Release 说明。

建议发布说明使用以下表格：

| STM32 | Himax | ESP32-S3 | SD 卡 | Desktop | App | SDK |
| --- | --- | --- | --- | --- | --- | --- |
| 见 Release | 见 Release | 见 Release | 见 Release | 见 Release | 见 Release | 见 Release |

烧录和写卡顺序见[烧录指南](flashing_zh.md)。

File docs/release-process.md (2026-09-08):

<p><strong>English</strong> | <a href="release-process_zh.md">简体中文</a></p>

# Release Process

Release artifacts are managed through GitHub Releases, not committed to Git.

Recommended tag names:

- full product set: `watche-vX.Y.Z`
- firmware only: `firmware-vX.Y.Z`
- hardware only: `hardware-vX.Y.Z`
- Android app: `app-vX.Y.Z`
- server package: `server-vX.Y.Z`
- desktop installer: `desktop-vX.Y.Z`

Each release should include:

- release notes
- compatibility matrix
- component versions recorded in the release notes
- `SHA256SUMS.txt`
- a machine-readable bundle manifest
- all required downloadable artifacts

A full public test release includes the ESP32-S3 + Himax PTL paired ZIP, STM32 ZIP, device SD-card `.tar.gz`, Python SDK wheel, Windows x64 installer, macOS aarch64 DMG, Android APK, bundle manifest, and `SHA256SUMS.txt`. Its iOS build is distributed through the TestFlight entry in the release notes. Standalone ESP32-S3, standalone Himax, and separate Skill packages are unnecessary when the PTL paired ZIP already contains both binaries, cross-platform tools, and the paired Skill.

Large binaries, firmware packages, APKs, installers, DMGs, resource archives, Gerber ZIPs, and hardware package ZIPs must be uploaded as release assets rather than committed to Git.

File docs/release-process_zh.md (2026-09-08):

<p><a href="release-process.md">English</a> | <strong>简体中文</strong></p>

# 发布规则

发布文件通过 GitHub Releases 分发，不提交到 Git 历史。

完整 Release 应包含：

- ESP32-S3 + Himax 配套 ZIP
- STM32 ZIP
- SD 卡资源压缩包
- Python SDK wheel
- Windows、macOS 和 Android 安装包
- iOS TestFlight 入口
- bundle manifest、校验文件和发布说明

配套 ZIP 已包含两个芯片的固件、工具和 Skill 时，不再单独上传重复附件。

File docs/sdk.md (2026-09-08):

English | [简体中文](sdk_zh.md)

# SDK Installation and Commands

Complete robot flashing, SD-card preparation, and network setup first. Download the `watcherobot` `.whl` from the [Latest Release](https://github.com/orulink-ai/WatcheRobot-public/releases/latest), then open a terminal in the folder containing it.

## 1. Create the Environment and Install

```bash
conda create -n watcherobot-sdk python=3.12 pip -y
conda activate watcherobot-sdk
```

Windows PowerShell:

```powershell
$wheel = Get-Item .\watcherobot-*.whl
python -m pip install $wheel.FullName
watcherobot --version
```

macOS/Linux:

```bash
python -m pip install ./watcherobot-*.whl
watcherobot --version
```

## 2. Set Up and Connect the Robot

For first-time network setup, run this on a Bluetooth-capable Windows or macOS computer:

```bash
watcherobot robot setup
```

After the robot is online, connect the computer to the same network and open the Python SDK app on the robot. Replace `123456` with the six-digit pairing code shown on screen:

```bash
watcherobot robot pair 123456
watcherobot robot status
```

## 3. Run a Python Script

```bash
python my_robot.py
```

Replace `my_robot.py` with your script file. See the [Python SDK README](../python-sdk/README.md) for APIs and examples.

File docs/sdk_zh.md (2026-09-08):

[English](sdk.md) | 简体中文

# SDK 安装与运行

先完成机器人烧录、SD 卡准备和联网。从 [Latest Release](https://github.com/orulink-ai/WatcheRobot-public/releases/latest) 下载 `watcherobot` 的 `.whl` 文件，在该文件所在目录打开终端。

## 1. 创建环境并安装

```bash
conda create -n watcherobot-sdk python=3.12 pip -y
conda activate watcherobot-sdk
```

Windows PowerShell：

```powershell
$wheel = Get-Item .\watcherobot-*.whl
python -m pip install $wheel.FullName
watcherobot --version
```

macOS/Linux：

```bash
python -m pip install ./watcherobot-*.whl
watcherobot --version
```

## 2. 配置并连接机器人

首次配置网络时，在支持蓝牙的 Windows 或 macOS 电脑运行：

```bash
watcherobot robot setup
```

机器人联网后，让电脑连接同一网络，并在机器人上打开 Python SDK 应用。将 `123456` 换成屏幕显示的六位配对码：

```bash
watcherobot robot pair 123456
watcherobot robot status
```

## 3. 运行 Python 脚本

```bash
python my_robot.py
```

将 `my_robot.py` 换成自己的脚本文件。API 和示例见 [Python SDK 中文说明](../python-sdk/README.zh-CN.md)。

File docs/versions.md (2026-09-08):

English | [简体中文](versions_zh.md)

# Version Sources

Public users should start from the [Latest Release](https://github.com/orulink-ai/WatcheRobot-public/releases/latest). These guides do not pin product versions; each Release records its component versions.

| Area | Where to find its version |
| --- | --- |
| Complete public release | Release tag and notes |
| STM32, Himax, ESP32-S3 | Release notes and firmware package names |
| SD-card resources | Release notes and resource archive name |
| Windows, macOS, Android, iOS | Release notes and download entry |
| Python SDK | Release notes, wheel name, and `python-sdk/pyproject.toml` |
| Hardware files | Production files under `hardware/` |

The root `VERSION` identifies the repository material package; it does not replace component release versions.

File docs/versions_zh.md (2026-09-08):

[English](versions.md) | 简体中文

# 版本来源

公开使用者以 [Latest Release](https://github.com/orulink-ai/WatcheRobot-public/releases/latest) 为下载入口。正文不固定具体版本号；每次发布时由 Release 页面记录各部分版本。

| 部分 | 版本信息位置 |
| --- | --- |
| 整套公开发布 | Release 标签和说明 |
| STM32、Himax、ESP32-S3 | Release 说明及固件包名称 |
| SD 卡资源 | Release 说明及资源包名称 |
| Windows、macOS、Android、iOS | Release 说明和对应下载入口 |
| Python SDK | Release 说明、wheel 名称和 `python-sdk/pyproject.toml` |
| 硬件资料 | `hardware/` 中的生产文件 |

仓库根目录的 `VERSION` 表示仓库资料包版本，不代替各组件的发布版本。

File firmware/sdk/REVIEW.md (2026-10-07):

# 合并前鲁棒性审查（开发预览）

日期：2026-10-07。范围：新增 SDK 适配层、身体事件运行层、运动结果关联、
显示/音频 BSP 生命周期改动和独立示例。不是对全部第三方驱动的全量审计。

## Blockers

None found（仅针对开发预览合并；完整稳定版发布门禁见 VALIDATION.md）。

## High Risk

已修复：身体静默误失联与 UART 门禁竞争导致永久 FAULT；分发期间关闭或并发
关闭可能使借用上下文/工作任务失效。修复在既有服务与 SDK 生命周期层完成，
不新增第二套 UART 协议。回归测试先失败再通过，超时关闭仍可重试。

## Medium/Low

已修复：通用 ACK/NACK 被误报为运动生命周期；既有运动服务增加有界序列关联，
保留 typed DONE/FAULT（包括停止之前的原运动结果）。最近 32 命令以外的迟到
ACK/NACK 不报告，调用方不应把 ACK 当作完成。板级共享总线与部分 LVGL 缓存
保留至进程结束，这是公开资源约定，不承诺关闭全部回收。

## Missing Verification

完整机械限位、全部灯光分区/触摸类型、JPEG 解码/流重启、PCM 品质、
缺失设备隔离、多核并发压力及恢复官方流程仍待实机验收。先前双 MCU HIL
证明命令执行链路，并非最后审查补充代码的硬件重测或精确机械位置证据。
最终合入必须重新通过 CI；不得据此发布稳定首版。

## No Finding Areas

已检查：模块依赖隔离；有界 FIFO 和溢出计数；每帧触摸复制；未就绪拒绝及
重连不重放；角度/时长校验；JPEG 回调借用约定；音频 codec lease 与单 owner
阻塞约定；标准显示句柄、LVGL 锁、DMA 排空和失败时保留资源的退出路径。

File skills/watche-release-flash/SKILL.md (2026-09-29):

---
name: watche-release-flash
description: Prepare tools automatically and flash released WatcheRobot STM32 or paired Himax/ESP32 firmware through the repository launchers.
---

English | [简体中文](SKILL_zh.md)

# Released Firmware Flashing

Use the repository's `tools/flash.ps1` on Windows or `tools/flash.sh` on macOS/Linux. Follow the guide to create and activate a dedicated named Conda environment (example: `watcherobot`). If that name already exists, create a different new name; never reuse an existing environment without user approval. The scripts reject base and mismatched interpreters and prepare dependencies and flashing tools. Never install dependencies into base, user-site, or another existing Python environment. Do not change global PATH or Conda configuration. Missing Conda is a prerequisite, not a reason to fall back to system Python.

Read [the guide](../../docs/flashing.md). Resolve the extracted firmware folder and the authorized target. For STM32, pass `stm32 --package <folder-containing-bin>`. For the head, pass `head --package <paired-folder> --port <control> --vision-port <vision>`. Resolve paths relative to the repository; quote paths with spaces.

For head flashing, SERIAL-B / MI_02 is the ESP32 control port passed to `--port`; SERIAL-A / MI_00 is the Himax port passed to `--vision-port`. First run the head command without ports and use the script's three-column mapping to obtain the arguments; use the guide's read-only port query when a second check is useful. Confirm both belong to the same CH342 USB serial number. The launcher checks the A/B roles; if they are reversed, stop and use the reported mapping. The repository orchestrator checks the package and ports, flashes ESP32, starts it and confirms Himax power initialization, flashes Himax, then restarts. Use one head command without intermediate confirmation prompts. Do not invoke the package's older paired-flash entry directly, alter firmware binaries, or replace the selected release.

For the initial full installation of the public Release, append `--factory` so the ESP32 partition table, application, and storage all come from the same package. This overwrites existing ESP32 data. If an existing device must preserve data, stop and explain the distinction; do not silently turn an update request into a full installation.

`--prepare-only` downloads and checks tools without accessing hardware. It is not hardware acceptance. Windows driver installation may require administrator privileges; preserve OS prompts and stop on failure. Driver download failure must not be reported as successful preparation. CH342 driver auto-install and Linux permission setup are not yet implemented; report these limitations if encountered.

For STM32, require exit code zero and OpenOCD's Programming Finished, Verified OK, and Resetting Target messages. For the head, require the Himax completion, PTL paired completion, and repository-entry completion messages in sequence. Never report simulations or environment preparation as a successful flash. Install SD resources only through a card reader and the repository writer.

Perform whole-device acceptance only after reinserting the SD card and powering on: reach the normal interface, open Phone Control, connect the phone over BLE, play one SD-backed expression, and run one small movement. The first Phone Control entry may need a few seconds for BLE and the STM32 link to initialize. If any check fails, report the verified stage precisely; a successful write is not by itself a successful whole-device acceptance.

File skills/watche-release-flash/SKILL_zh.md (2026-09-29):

[English](SKILL.md) | 简体中文

# 发布固件烧录

Windows 使用仓库 `tools/flash.ps1`，macOS/Linux 使用 `tools/flash.sh`。按指南用 Conda 新建并进入命名环境（示例 `watcherobot`）；同名环境已存在时换一个新名字，未经用户确认不复用已有环境。其余依赖和烧录工具由脚本准备。入口拒绝 base 和解释器不匹配的环境，禁止向 base、用户包目录或其他已有 Python 环境安装依赖，不修改全局 PATH 和 Conda 配置。缺少 Conda 时说明前置条件，不回退到系统 Python。

先读[烧录指南](../../docs/flashing_zh.md)，确定已解压固件目录和用户授权的目标。STM32 参数为 `stm32 --package <包含bin的目录>`；头部参数为 `head --package <配套包目录> --port <控制口> --vision-port <视觉口>`。路径以仓库目录为基准，含空格时加引号。

头部 SERIAL-B / MI_02 为 ESP32 控制口，填写 `--port`；SERIAL-A / MI_00 为 Himax 口，填写 `--vision-port`。先运行不带端口的头部命令，使用脚本打印的三列表确认实际参数；需要复查时使用指南中的只读端口查询命令。确认两者 USB serial number 相同。入口会检查 A/B 角色，填反时必须停止并按提示修正。仓库统一流程为：检查 → 烧录 ESP32 → 启动并确认 Himax 供电初始化 → 烧录 Himax → 重启。只用一条头部命令，中途不增加输入确认，不直接调用发布包中旧的双芯片烧录入口。不改固件、不换版本。

公开 Release 的首次完整安装必须在头部命令末尾添加 `--factory`，让 ESP32 分区表、应用和 storage 来自同一发布包。该参数会覆盖原有 ESP32 数据；已有设备要求保留数据时停止并说明，不把更新请求擅自改成完整安装。

`--prepare-only` 仅下载和检查工具，不访问硬件，不算实机验收。Windows 驱动安装可能触发管理员权限要求，保留系统提示，失败即停止。驱动下载失败不能报告准备完成。CH342 自动驱动安装及 Linux 权限配置目前尚未实现，遇到时如实报告。

STM32 要求退出码为零，并包含 Programming Finished、Verified OK、Resetting Target。头部要求依次出现 Himax 完成、PTL paired 完成和仓库入口完成提示。模拟和环境准备不能代替实际烧录成功。SD 卡仅通过读卡器和仓库写卡脚本安装资源。

SD 卡插回并上电后再做整机验收：正常进入主界面；Phone Control 能打开；手机 BLE 能连接；一个 SD 表情资源可播放；一个小幅动作能完成。首次打开 Phone Control 可等待几秒完成 BLE 和 STM32 链路初始化。若某项失败，只报告已确认的阶段，不把“烧录成功”等同于“整机功能通过”。

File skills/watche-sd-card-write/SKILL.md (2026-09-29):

---
name: watche-sd-card-write
description: Download, verify, and install official WatcheRobot resources to a FAT32 SD card through a card reader using the repository's cross-platform writer.
---

English | [简体中文](SKILL_zh.md)

# WatcheRobot SD-card Writing

Read [the SD-card guide](../../docs/sd-card-assets.md). Use only a card reader and the repository launchers. Require the dedicated non-base Conda environment described in the flashing guide; never install into or alter another Python environment.

Resolve the exact SD-card root before writing. On Windows use `powershell -NoProfile -ExecutionPolicy Bypass -File tools/flash.ps1 sd --drive "E:\"`. On macOS/Linux use `bash tools/flash.sh sd --drive "/Volumes/WATCHE"`. Replace the example target with the actual card. Never guess a drive or mount point, and never select a system drive.

Without `--package`, the writer downloads the latest official package. For a Release archive, append `--package <watche-sd-resources-*.tar.gz>`. Do not manually extract the release archive: the writer validates it and maps it into the device's `watche/` layout.

The card must use FAT32 with a 512-byte allocation unit. Windows users can select these settings in the card's Format dialog, or run `powershell -NoProfile -ExecutionPolicy Bypass -File tools/flash.ps1 sd-format --drive "E:\"` in an Administrator terminal with the dedicated Conda environment active. Formatting deletes all files, including resources and creator works: back them up first. Only format an identified card when the user authorizes formatting; a resource update alone does not authorize it. The command formats immediately without an additional confirmation prompt; check the target before running it. The formatter supports Windows removable drives only.

The writer must confirm FAT32, writable media, the package manifest, every file hash, and the final installed layout. Windows also checks the allocation unit; on macOS/Linux, confirm the 512-byte setting when preparing the card. Resource writing preserves creator works and uses staging before switching the official catalog. Do not delete unrelated files. Use `--force` only when the user explicitly asks to discard an unfinished device transaction.

Report card-writing success only after exit code zero and the final `Installed ... successfully` message. Then instruct the user to eject the card safely and insert it into the powered-off head. Device-side acceptance additionally requires a normal boot and one SD-backed expression to play; do not describe a successful computer-side write as proof that the robot read the card.

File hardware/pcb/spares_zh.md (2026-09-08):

<p><a href="spares.md">English</a> | <strong>简体中文</strong></p>

# 备用物料清单

用于记录现场准备的备用元件。

| 板卡 | 元件或位号 | 建议数量 | 购买链接 | 替代型号 | 存放位置 | 备注 |
| --- | --- | ---: | --- | --- | --- | --- |
| 身体主板 | 待填写 | 待填写 | 待填写 | 待填写 | 待填写 | 发布前填写 |
| 脚底充电板 | 待填写 | 待填写 | 待填写 | 待填写 | 待填写 | 发布前填写 |
| 无线充电底座 | 待填写 | 待填写 | 待填写 | 待填写 | 待填写 | 发布前填写 |
| 侧边灯板 | 待填写 | 待填写 | 待填写 | 待填写 | 待填写 | 发布前填写 |

备用元件应能对应到 BOM，并写清购买链接、替代型号和存放位置。

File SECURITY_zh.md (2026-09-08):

<p><a href="SECURITY.md">English</a> | <strong>简体中文</strong></p>

# 安全策略

## 公开仓库规则

不要向本仓库提交密钥或本机私有数据，包括：

- Wi-Fi 名称或密码
- API key、Token、私钥或证书
- `.env` 文件或本地认证请求头
- 会暴露个人电脑、账号或网络信息的串口日志
- 未公开的 App、服务端或桌面端源码

仓库策略检查会扫描常见密钥模式和私有路径，但提交前仍需自行检查改动。

## 报告敏感问题

如果问题可以在不暴露密钥的情况下描述，可以创建 GitHub Issue，并在标题或首段注明安全相关。

如果必须提供凭证、私有日志或未公开的漏洞细节，请勿粘贴到公开 Issue。请通过组织账号或已有的私有支持渠道联系维护者，只提供复现问题所需的最少信息。

## 支持范围

本公开仓库接受以下范围的安全报告：

- `tools/` 中公开的烧录与发布工具
- `docs/` 中公开的使用文档
- 影响安全复现的硬件公开资料

未公开的 App、服务端和桌面端软件通过其他渠道维护。

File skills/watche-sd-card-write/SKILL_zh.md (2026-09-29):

---
name: watche-sd-card-write-zh
description: 通过读卡器和仓库跨平台脚本下载、校验并写入 WatcheRobot 官方 SD 卡资源。
---

[English](SKILL.md) | 简体中文

# WatcheRobot SD 卡写入

先读 [SD 卡资源说明](../../docs/sd-card-assets_zh.md)。只使用读卡器和仓库脚本；使用烧录指南中的专用非 base Conda 环境，不向其他 Python 环境安装内容，也不修改其他环境。

写入前确认准确的 SD 卡盘符或挂载点。Windows 使用 `powershell -NoProfile -ExecutionPolicy Bypass -File tools/flash.ps1 sd --drive "E:\"`；macOS/Linux 使用 `bash tools/flash.sh sd --drive "/Volumes/WATCHE"`。示例路径必须换成实际 SD 卡，不能猜测盘符或选择系统盘。

不写 `--package` 时，脚本自动下载最新官方包。使用 Release 中的资源包时，在命令末尾添加 `--package <watche-sd-resources-*.tar.gz>`。不要手工解压发布归档；脚本会校验并转换成设备使用的 `watche/` 布局。

SD 卡须为 FAT32，分配单元大小 512 字节。Windows 可在 SD 卡的格式化窗口选择，或在管理员终端激活专用 Conda 环境后运行 `powershell -NoProfile -ExecutionPolicy Bypass -File tools/flash.ps1 sd-format --drive "E:\"`。格式化会删除全部文件，包括资源和用户作品，须先备份。只有用户授权格式化且目标卡已确认时才执行；单纯更新资源不代表授权格式化。命令执行后直接格式化，不再二次确认，运行前须核对目标盘符。格式化脚本仅支持 Windows 可移动盘。

写入脚本必须确认 FAT32、介质可写、压缩包清单、逐文件哈希和最终目录；Windows 还会检查分配单元，macOS/Linux 须在准备卡时确认 512 字节设置。资源写入通过 staging 切换官方资源，同时保留用户作品。不得删除无关文件；只有用户明确要求丢弃未完成的设备事务时才可使用 `--force`。

只有退出码为零且最后出现 `Installed ... successfully` 才能报告写卡成功。随后提醒用户安全弹出 SD 卡，并在机器人断电状态下插回头部。上电后能进入正常界面并播放一个表情，才算设备已经读取这套 SD 资源；不要把电脑端写卡成功直接表述为设备读取成功。

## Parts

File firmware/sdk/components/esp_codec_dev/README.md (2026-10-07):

# ESP Codec Device
- 
- [中文版本](./README_CN.md)

## General Information

`esp_codec_dev` is a driver component for audio codec devices. Following features are supported currently:
* Support driver for common audio codec devices
* Support multiple instance of codec devices (including device of same type)
* Add unified abstract interface to operate on codec device
* Support customized codec realization based on provided interface
* Easy-to-use high-level API for playback and recording
* Support for volume adjustment in software when it is not supported in hardware
* Support customized volume curve and customized volume control
* Easy to port to other platform after replacing codes under [platform](./platform)

The currently supported codec devices are listed as below:

| |Playback|Record|
| :-----| :---- | :---- |
|ES8311  |Y|Y|
|ES8388  |Y|Y|
|ES8374  |Y|Y|
|ZL38063  |Y|Y|
|TAS6805M  |Y|N|
|AW88298 |Y|N|
|ES7210 |N|Y|
|ES7243 |N|Y|
|ES7243E |N|Y|
|ES8156 |N|Y|

## Architecture overview

Hardware connection and software architecture are introduced respectively by taking the codec device (ES8311) as an example.  
The hardware connection diagram between the codec device (ES8311) and the main IC (ESP32-S3) is as below:
```mermaid
graph LR;
    subgraph Mic
       Microphone
    end
    subgraph ESP32-S3
       I2C_Bus
       I2S_Bus
       PA_GPIO
    end
    subgraph ES8311
      ADC
      DAC
      I2C_Port
      I2S_Port
    end
    subgraph NS4150
      IN
      CTRL
      OUT
    end
    subgraph "Left Speaker"
      Speaker
    end
    I2C_Bus --> I2C_Port
    I2S_Bus --> I2S_Port
    DAC --> IN
    OUT --> Speaker
    PA_GPIO --> CTRL
    Microphone --> ADC
```

ESP32-S3 sends control data to ES8311 through I2C bus and exchanges audio data through I2S bus. During playing, ES8311 receives digital audio data from I2S bus and performs DAC operation, then the analog signal is amplified by PA chip (NS4150) and finally is output through the speaker. During recording, ES8311 gets the analog signal from the microphone, amplifies it, and performs ADC operation, then digital audio data can be obtained from ESP32-S3.

Communication between ESP32-S3 and ES8311 mainly occurs on two paths:
* Control path: Set up the codec chip (using I2C bus)
* Data path: Exchange audio data (using I2S bus)
   
In software architecture, the above hardware behavior is abstracted as:
```mermaid
classDiagram
direction LR;
class audio_codec_ctrl_if_t {
	open()
	read_reg()
	write_reg()
	close()    
}

class audio_codec_gpio_if_t {
	setup()
	set()
	get()
}

class es8311_codec_cfg_t {
    audio_codec_ctrl_if_t *ctrl_if
    audio_codec_gpio_if_t *gpio_if
    int16_t pa_pin
    esp_codec_dev_hw_gain_t hw_gain
}

class audio_codec_if_t {
	audio_codec_ctrl_if_t* ctrl_if
	open()
	enable()
	set_fs()
	set_vol()
	set_mic_gain()
	close()
}

class audio_codec_data_if_t {
	open()
	set_fmt()
	read()
	write()
	close()
}

class esp_codec_dev {
	audio_codec_data_if_t* data_if
	audio_codec_if_t* codec_if
	esp_codec_dev_new()
	esp_codec_dev_open()
	esp_codec_dev_read()
	esp_codec_dev_write()
	esp_codec_dev_set_out_vol()
	esp_codec_dev_set_in_gain()
	esp_codec_dev_set_vol_curve()
	esp_codec_dev_set_vol_handler()
	esp_codec_dev_close()
}

audio_codec_ctrl_if_t ..> es8311_codec_cfg_t
audio_codec_gpio_if_t ..> es8311_codec_cfg_t
es8311_codec_cfg_t ..> audio_codec_if_t
audio_codec_if_t ..> esp_codec_dev
audio_codec_data_if_t ..> esp_codec_dev
```

`esp_codec_dev` abstracts the above communication path into two interfaces:  
* `audio_codec_ctrl_if_t` for the control path:  
	The control interface mainly offers `read_reg` and `write_reg` APIs to do codec setup  
	Commonly used control channels include I2C, SPI, etc
* `audio_codec_data_if_t` for data path:  
	The data interface mainly offers `read` and `write` APIs to exchange audio data  
	Commonly used data channels include I2S, SPI, etc

`esp_codec_dev` provides users with convenient high-level API to implement playback and recording functions. It is composed of `audio_codec_data_if_t` and `audio_codec_if_t`. `audio_codec_if_t` abstracts codec control operations and constructed by specified codec configuration (configured by `audio_codec_ctrl_if_t` and `audio_codec_gpio_if_t` through `es8311_codec_cfg_t`). `audio_codec_gpio_if_t` abstracts the IO control to adapt to the main control IO or the expansion chip IO, and called inside the codec to match the unique set timing.

## DAC Volume setting

Volume setting is realized by common API: `esp_codec_dev_set_out_vol`.  
`esp_codec_dev` supports the following volume setup methods:
1. Use codec register to adjust the volume
2. Use built-in software volume `audio_codec_new_sw_vol` when codec hardware does not support volume adjustment
3. Use customized software volume interface through `esp_codec_dev_set_vol_handler`

The default volume range is 0 - 100. Volume [1:100] is mapped to [-49.5 dB:0 dB] with the scale being 0.5 dB. Volume 0 is mapped to -96 dB. To change this mapping, you can define your own volume curve through API `esp_codec_dev_set_vol_curve`. The volume curve is an array of `esp_codec_dev_vol_map_t` which uses linear interpolation to calculate the decibel value at a certain volume point internally (please sort volume maps in advance).   
To balance the speaker's loudness across different platforms when playing the same content, you need to know some mechanism of the audio gain. In short, audio gain consists of two parts: software gain (adjustable) and hardware gain (fixed). Software gain can be adjusted by changing the input PCM data level or setting the codec volume register. The hardware gain is affected by the peripheral circuit, mainly by the amplification efficiency of the analog signal. The typical impact parameter of hardware gain is extracted into `esp_codec_dev_hw_gain_t`, which can be configured to codec devices to ensure loudness consistency. For more details, please refer to the comments in [esp_codec_dev_vol.h](include/esp_codec_dev_vol.h).

## Usage

The steps below take the ES8311 codec as an example to illustrate how to play and record audio.
1. Install the driver for codec control and data bus referring to [test_board.c](test_apps/codec_dev_test/main/test_board.c)  
   	```c
	ut_i2c_init(0);
	ut_i2s_init(0);
   	```
2. Create the control and data interfaces for the codec using the interface provided by default   
   	```c
	audio_codec_i2s_cfg_t i2s_cfg = {
	#if ESP_IDF_VERSION >= ESP_IDF_VERSION_VAL(5, 0, 0)
	    .rx_handle = i2s_keep[0]->rx_handle,
	    .tx_handle = i2s_keep[0]->tx_handle,
	#endif
	};
	const audio_codec_data_if_t *data_if = audio_codec_new_i2s_data(&i2s_cfg);

	audio_codec_i2c_cfg_t i2c_cfg = {.addr = ES8311_CODEC_DEFAULT_ADDR};
	const audio_codec_ctrl_if_t *out_ctrl_if = audio_codec_new_i2c_ctrl(&i2c_cfg);

	const audio_codec_gpio_if_t *gpio_if = audio_codec_new_gpio();
   	```

3. Create the codec interface based on control interface and codec-specified configuration  
   	```c
	es8311_codec_cfg_t es8311_cfg = {
	    .codec_mode = ESP_CODEC_DEV_WORK_MODE_BOTH,
	    .ctrl_if = out_ctrl_if,
	    .gpio_if = gpio_if,
	    .pa_pin = YOUR_PA_GPIO,
	    .use_mclk = true,
	};
	const audio_codec_if_t *out_codec_if = es8311_codec_new(&es8311_cfg);
   	```

4. Get `esp_codec_dev_handle_t` through `esp_codec_dev_new`  
   Now you can use the handle for further playback and recording as follows:
	```c
	esp_codec_dev_cfg_t dev_cfg = {
		.codec_if = out_codec_if;              // codec interface from es8311_codec_new
		.data_if = data_if;                    // data interface from audio_codec_new_i2s_data
		.dev_type = ESP_CODEC_DEV_TYPE_IN_OUT; // codec support both playback and record
	};
	esp_codec_dev_handle_t codec_dev = esp_codec_dev_new(&dev_cfg);
	// Below code shows how to play
	esp_codec_dev_set_out_vol(codec_dev, 60.0);
	esp_codec_dev_sample_info_t fs = {
		.sample_rate = 48000,
		.channel = 2,
		.bits_per_sample = 16,
	};
	esp_codec_dev_open(codec_dev, &fs);
	uint8_t data[256];
	esp_codec_dev_write(codec_dev, data, sizeof(data));

	// Below code shows how to record
	esp_codec_dev_set_in_gain(codec_dev, 30.0);
	esp_codec_dev_read(codec_dev, data, sizeof(data));
	esp_codec_dev_close(codec_dev);
	```

## How to customize for new codec device

1. Implement `audio_codec_ctrl_if_t` and `audio_codec_data_if_t`  
   If you are using I2C bus for control and I2S bus for data, you can use the implementation provided by default:  
   `audio_codec_new_i2c_ctrl` and `audio_codec_new_i2s_data`

2. Implement `audio_codec_if_t` based on the interface built in step 1
	```c
	typedef struct {
		const audio_codec_ctrl_if_t *ctrl_if;     /*!< Codec Control interface */
		const audio_codec_gpio_if_t *gpio_if;     /*!< If you want to operate GPIO */
		//...................................     Other settings
	} my_codec_cfg_t;
	const audio_codec_if_t *my_codec_new(my_codec_cfg_t *codec_cfg);
	```

For details, refer to the sample code [my_codec.c](test_apps/codec_dev_test/main/my_codec.c).

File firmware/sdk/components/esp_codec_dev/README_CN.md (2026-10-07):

# ESP Codec Device
- 
- [English version](./README.md)

## 概要

`esp_codec_dev` 是为音频编解码器设备提供驱动的组件，目前支持以下功能:
* 提供常用音频编解码器设备的驱动
* 支持音频编解码器设备的多实例 （包括同类型设备）
* 提供统一的抽象化接口来操作编解码器设备
* 支持客户定制化编解码器设备 (仅需实例化提供的接口)
* 为播放和录音提供易用的上层 API
* 支持软件音量调节 (硬件不支持音量调节时)
* 支持定制化音量曲线以及音量控制实现
* 兼容多平台仅需替换 [platform](./platform)

已经支持的编解码器设备如下:
| |播放|录音|
| :-----| :---- | :---- |
|ES8311  |Y|Y|
|ES8388  |Y|Y|
|ES8374  |Y|Y|
|ZL38063  |Y|Y|
|TAS6805M  |Y|N|
|AW88298 |Y|N|
|ES7210 |N|Y|
|ES7243 |N|Y|
|ES7243E |N|Y|
|ES8156 |N|Y|

## 架构预览

以编解码器设备 (ES8311) 为例，下面分别介绍硬件框图和软件架构。  
编解码器设备 (ES8311) 和主芯片(ESP32-S3) 之间的硬件连接简图如下:
```mermaid
graph LR;
    subgraph "麦克风"
      Microphone
    end
    subgraph ESP32-S3
       I2C总线
       I2S总线
       PA_GPIO
    end
    subgraph ES8311
      ADC
      DAC
      I2C端口
      I2S端口
    end
    subgraph NS4150
      IN
      CTRL
      OUT
    end
    subgraph "扬声器"
      Speaker
    end
    I2C总线 --> I2C端口
    I2S总线 --> I2S端口
    DAC --> IN
    OUT --> Speaker
    PA_GPIO --> CTRL
    Microphone --> ADC
```

ESP32-S3 通过 I2C 总线向 ES8311 发送控制命令，通过 I2S 总线传递音频数据。在播放过程中, ES8311 从 I2S 总线接收数字音频数据进行数模转换后发送给功放芯片(NS4150), 最后发送给扬声器输出声音。在录音过程中，ES8311将从麦克风采集到的模拟信号放大，进行模数转换后发送给 ESP32-S3。
ESP32-S3 同 ES8311 在以下两个通道进行通讯:
 1. 控制通道：用来配置编解码器设备 (通过 I2C 总线)
 2. 数据通道: 用来交换音频数据 (通过 I2S 总线)

软件架构上，对硬件行为进行了下述抽象：
```mermaid
classDiagram
direction LR;
class audio_codec_ctrl_if_t {
	open()
	read_reg()
	write_reg()
	close()    
}

class audio_codec_gpio_if_t {
	setup()
	set()
	get()
}

class es8311_codec_cfg_t {
    audio_codec_ctrl_if_t *ctrl_if
    audio_codec_gpio_if_t *gpio_if
    int16_t pa_pin
    esp_codec_dev_hw_gain_t hw_gain
}

class audio_codec_if_t {
	audio_codec_ctrl_if_t* ctrl_if
	open()
	enable()
	set_fs()
	set_vol()
	set_mic_gain()
	close()
}

class audio_codec_data_if_t {
	open()
	set_fmt()
	read()
	write()
	close()
}

class esp_codec_dev {
	audio_codec_data_if_t* data_if
	audio_codec_if_t* codec_if
	esp_codec_dev_new()
	esp_codec_dev_open()
	esp_codec_dev_read()
	esp_codec_dev_write()
	esp_codec_dev_set_out_vol()
	esp_codec_dev_set_in_gain()
	esp_codec_dev_set_vol_curve()
	esp_codec_dev_set_vol_handler()
	esp_codec_dev_close()
}

audio_codec_ctrl_if_t ..> es8311_codec_cfg_t
audio_codec_gpio_if_t ..> es8311_codec_cfg_t
es8311_codec_cfg_t ..> audio_codec_if_t
audio_codec_if_t ..> esp_codec_dev
audio_codec_data_if_t ..> esp_codec_dev
```

通讯通道抽象为两种接口: 
* `audio_codec_ctrl_if_t` 控制接口：
	主要提供 `read_reg` 和 `write_reg` API 来配置编解码器设备  
	常用控制通道包括 I2C， SPI 等
* `audio_codec_data_if_t` 数据接口：
	主要提供 `read` 和 `write` API 用来交换音频数据  
	常用数据通道包括 I2S， SPI 等

`esp_codec_dev` 为用户提供便捷的上层 API 来实现播放和录音功能。它是由 `audio_codec_data_if_t` 和 `audio_codec_if_t` 组成。`audio_codec_if_t` 对编解码器控制操作进行抽象，通过编解码器特有的配置参数构建（由 `audio_codec_ctrl_if_t` 和`audio_codec_gpio_if_t` 通过 `es8311_codec_cfg_t` 进行配置）。`audio_codec_gpio_if_t ` 对 IO 控制进行抽象，以适配主控 IO 或者扩展芯片 IO， 在编解码器内部进行调用用以匹配特有的设定时序。

## 解码器音量设定

音量统一通过 API `esp_codec_dev_set_out_vol` 进行设定。  
`esp_codec_dev` 支持以下音量设定实现:
1. 通过调节音量寄存器实现
2. 在硬件不支持音量调节下，可以使用内置的软件音量实现 `audio_codec_new_sw_vol`
3. 客制化音量接口实现，并通过 `esp_codec_dev_set_vol_handler` 设定

默认的音量调节区间是 0 - 100，音量 100 对应为 0 dB，每个刻度对应 0.5 dB，音量 0 被特殊映射为 -96 dB。用户可以通过 `esp_codec_dev_set_vol_curve` 设定音量曲线来改变这一行为。音量曲线是音量映射 `esp_codec_dev_vol_map_t` 的数组，通过线性插值的方法来计算每一个音量对应的 dB 值 (请预先将音量映射排好序)。

为了平衡在不同平台上播放相同内容的响度差异，需要了解音频增益的相关机制。简单说来音频增益包括软件增益 （可调节）和硬件增益 (不可调节) 两部分。软件增益可以通过改变音频数据的幅值或者改变音量寄存器实现。硬件增益受外围电路的影响，主要取决于模拟信号的放大系数。实现中选取了典型的影响参数 `esp_codec_dev_hw_gain_t`，作为配置参数进行配置，以抵消平台间响度差异，详情可参考代码注释 [esp_codec_dev_vol.h](include/esp_codec_dev_vol.h)。

## 使用方法

以 ES8311 为例，下面将演示播放和录音的具体步骤
1. 为编解码器设备的控制和数据总线安装驱动，可参考[test_board.c](test_apps/codec_dev_test/main/test_board.c)   
   	```c
	ut_i2c_init(0);
	ut_i2s_init(0);
   	```
 
2. 为编解码器设备实现控制接口，数据接口和 GPIO 接口 (使用默认提供的接口实现)   
   	```c
	audio_codec_i2s_cfg_t i2s_cfg = {
	#if ESP_IDF_VERSION >= ESP_IDF_VERSION_VAL(5, 0, 0)
	    .rx_handle = i2s_keep[0]->rx_handle,
	    .tx_handle = i2s_keep[0]->tx_handle,
	#endif
	};
	const audio_codec_data_if_t *data_if = audio_codec_new_i2s_data(&i2s_cfg);

	audio_codec_i2c_cfg_t i2c_cfg = {.addr = ES8311_CODEC_DEFAULT_ADDR};
	const audio_codec_ctrl_if_t *out_ctrl_if = audio_codec_new_i2c_ctrl(&i2c_cfg);

	const audio_codec_gpio_if_t *gpio_if = audio_codec_new_gpio();
   	```

3. 基于控制接口和 ES8311 特有的配置实现 `audio_codec_if_t` 接口  
   	```c
	es8311_codec_cfg_t es8311_cfg = {
	    .codec_mode = ESP_CODEC_DEV_WORK_MODE_BOTH,
	    .ctrl_if = out_ctrl_if,
	    .gpio_if = gpio_if,
	    .pa_pin = YOUR_PA_GPIO,
	    .use_mclk = true,
	};
	const audio_codec_if_t *out_codec_if = es8311_codec_new(&es8311_cfg);
   	```

4. 通过 API `esp_codec_dev_new` 获取 `esp_codec_dev_handle_t` 句柄  
   参考下面代码用获取到的句柄来进行播放和录制操作:
	```c
	esp_codec_dev_cfg_t dev_cfg = {
		.codec_if = out_codec_if;              // es8311_codec_new 获取到的接口实现
		.data_if = data_if;                    // audio_codec_new_i2s_data 获取到的数据接口实现
		.dev_type = ESP_CODEC_DEV_TYPE_IN_OUT; // 设备同时支持录制和播放
	};
	esp_codec_dev_handle_t codec_dev = esp_codec_dev_new(&dev_cfg);
	// 以下代码展示如何播放音频
	esp_codec_dev_set_out_vol(codec_dev, 60.0);
	esp_codec_dev_sample_info_t fs = {
		.sample_rate = 48000,
		.channel = 2,
		.bits_per_sample = 16,
	};
	esp_codec_dev_open(codec_dev, &fs);
	uint8_t data[256];
	esp_codec_dev_write(codec_dev, data, sizeof(data));

	// 以下代码展示如何录制音频
	esp_codec_dev_set_in_gain(codec_dev, 30.0);
	esp_codec_dev_read(codec_dev, data, sizeof(data));
	esp_codec_dev_close(codec_dev);
	```

## 客制化编解码器设备

1. 实现接口 `audio_codec_ctrl_if_t` 和 `audio_codec_data_if_t`  
   如果使用 I2C 总线作控制，I2S 总线做数据传输，可以使用默认的接口实现：  
   `audio_codec_new_i2c_ctrl` 和 `audio_codec_new_i2s_data`

2. 在第一步的基础上实现接口 `audio_codec_if_t`
	```c
	typedef struct {
		const audio_codec_ctrl_if_t *ctrl_if;     /*!< 创建的控制接口 */
		const audio_codec_gpio_if_t *gpio_if;     /*!< 需要操作 GPIO */
		//...................................     其他设定
	} my_codec_cfg_t;
	const audio_codec_if_t *my_codec_new(my_codec_cfg_t *codec_cfg);
	```

更细节的实现可以参考测试代码 [my_codec.c](test_apps/codec_dev_test/main/my_codec.c)。

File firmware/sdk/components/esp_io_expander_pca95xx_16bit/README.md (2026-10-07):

# ESP IO Expander Chip PCA9539 and PCA9555



Implementation of the PCA9539 and PCA9555 io expander chip with esp_io_expander
component.

|  Chip | Communication interface | Component name | Link to datasheet |
| :-----: | :---: | :---: | :---: |
| PCA9539 | I2C | esp_io_expander_pca95xx_16bit | [datasheet](https://www.ti.com/lit/gpn/pca9539) |
| PCA9555 | I2C | esp_io_expander_pca95xx_16bit | [datasheet](https://www.ti.com/lit/gpn/pca9555) |

## Add to project

Packages from this repository are uploaded to
[Espressif's component service](https://components.espressif.com/). You can add
them to your project via `idf.py add-dependency`, e.g.

```
    idf.py add-dependency esp_io_expander_pca95xx_16bit==1.0.0
```

Alternatively, you can create `idf_component.yml`. More is in
[Espressif's documentation](https://docs.espressif.com/projects/esp-idf/en/latest/esp32/api-guides/tools/idf-component-manager.html).

## Example use

Creation of the component.

```
    esp_io_expander_handle_t io_expander = NULL;
    esp_io_expander_new_i2c_pca95xx_16bit(1, ESP_IO_EXPANDER_I2C_PCA9539_ADDRESS_00, &io_expander);
```

Set pin 0 and pin 1 with output dircetion and low level:

```
    esp_io_expander_set_dir(io_expander, IO_EXPANDER_PIN_NUM_0 | IO_EXPANDER_PIN_NUM_1, IO_EXPANDER_OUTPUT);
    esp_io_expander_set_level(io_expander, IO_EXPANDER_PIN_NUM_0 | IO_EXPANDER_PIN_NUM_1, 0);
```

Print all pins's status to the log:

```
    esp_io_expander_print_state(io_expander);
```

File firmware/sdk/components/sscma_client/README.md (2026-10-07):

# SSCMA Client



## Quick Start

Below is a minimal example for initializing and using the SSCMA Client component via UART, with English comments and no project-specific dependencies.

```c
#include "sscma_client_io.h"
#include "sscma_client_ops.h"
#include "driver/uart.h"
#include <stdio.h>
#include <string.h>
#include <assert.h>

static sscma_client_io_handle_t io = NULL;
sscma_client_handle_t client = NULL;

// Callback for inference result
typedef void (*sscma_client_event_cb_t)(sscma_client_handle_t, const sscma_client_reply_t *, void *);
void on_event(sscma_client_handle_t client, const sscma_client_reply_t *reply, void *user_ctx)
{
    printf("on_event: %s\n", reply->data);
}

void on_log(sscma_client_handle_t client, const sscma_client_reply_t *reply, void *user_ctx)
{
    printf("log: %s\n", reply->data);
}

void on_connect(sscma_client_handle_t client, const sscma_client_reply_t *reply, void *user_ctx)
{
    printf("on_connect\n");
}

void app_main(void)
{
    // 1. Initialize UART for SSCMA communication
    uart_config_t uart_config = {
        .baud_rate = 921600,
        .data_bits = UART_DATA_8_BITS,
        .parity = UART_PARITY_DISABLE,
        .stop_bits = UART_STOP_BITS_1,
        .flow_ctrl = UART_HW_FLOWCTRL_DISABLE,
        .source_clk = UART_SCLK_DEFAULT,
    };
    int intr_alloc_flags = 0;
    ESP_ERROR_CHECK(uart_driver_install(1, 8 * 1024, 0, 0, NULL, intr_alloc_flags));
    ESP_ERROR_CHECK(uart_param_config(1, &uart_config));
    ESP_ERROR_CHECK(uart_set_pin(1, 21, 20, -1, -1));

    // 2. Create SSCMA client UART IO
    sscma_client_io_uart_config_t io_uart_config = {
        .user_ctx = NULL,
    };
    sscma_client_new_io_uart_bus((sscma_client_uart_bus_handle_t)1, &io_uart_config, &io);

    // 3. Configure SSCMA client
    sscma_client_config_t sscma_client_config = SSCMA_CLIENT_CONFIG_DEFAULT();
    sscma_client_config.reset_gpio_num = GPIO_NUM_5; // Set your reset GPIO
    sscma_client_new(io, &sscma_client_config, &client);

    // 4. Register callbacks
    const sscma_client_callback_t callback = {
        .on_connect = on_connect,
        .on_event = on_event,
        .on_log = on_log,
    };
    sscma_client_register_callback(client, &callback, NULL);

    // 5. Initialize SSCMA client
    sscma_client_init(client);

    // 6. Set model and get info
    sscma_client_set_model(client, 1);
    sscma_client_info_t *info;
    if (sscma_client_get_info(client, &info, true) == ESP_OK) {
        printf("ID: %s\n", info->id ? info->id : "NULL");
        // ... print other info fields ...
    }

    // 7. Run inference
    if (sscma_client_invoke(client, -1, false, false) != ESP_OK) {
        printf("invoke failed\n");
    }

    // 8. Main loop
    while (1) {
        vTaskDelay(1000 / portTICK_PERIOD_MS);
    }
}
```

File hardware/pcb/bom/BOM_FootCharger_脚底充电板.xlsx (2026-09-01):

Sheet: BOM模板
序号 | 位号 | 数量 | 参数/型号 | 物料描述 | 封装 | 品牌/制造商 | 原厂料号 | LCSC编号 | 供应商 | 供应商料号 | 数据手册 | 贴装方式 | 可替代料 | 备注
1 | R1,R2 | 2 | 5.1kΩ | 5.1kΩ | R0603_3 | UNI-ROYAL(厚声) | 0603WAF5101T5E | C23186 | LCSC | C23186 |  | SMT |  | Type-C CC电阻
2 | U1 | 1 | YTC-TC6-268 | YTC-TC6-268 | TYPE-C-SMD_YIYUAN_YTC-TC6-268 | YIYUAN(怡远) | YTC-TC6-268 | C5260484 | LCSC | C5260484 |  | SMT |  | TYPE-C供电
3 | U2 | 1 | PR5L4015-3P-C-F | PR5L4015-3P-C-F | CONN-TH_PR5L4015-3P-C-F | SAMZO(三佐) | PR5L4015-3P-C-F | C41361290 | LCSC | C41361290 |  | THT |  | 无线充电接收磁吸pin
4 | VBUS测试点,灯光测试点 | 2 | Test-Point | Test-Point | Test-Point-0.5mm |  | Test-Point |  |  |  |  | DNP |  | 默认不贴装
5 | U3 | 1 | ZX-SH1.0-3PWT | ZX-SH1.0-3PWT | CONN-SMD_3P-P1.00_MEGASTAR_ZX-SH1.0-3PWT | Megastar(兆星) | ZX-SH1.0-3PWT | C7430445 | LCSC | C7430445 |  | SMT |  | 电源接线端子

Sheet: 填写示例
序号 | 位号 | 数量 | 参数/型号 | 物料描述 | 封装 | 品牌/制造商 | 原厂料号 | LCSC编号 | 供应商 | 供应商料号 | 数据手册 | 贴装方式 | 可替代料 | 备注
1 | R1,R2,R3 | 3 | 10k | 10k 1% 1/10W 电阻 | 0603 | YAGEO | RC0603FR-0710KL | C25804 | LCSC | C25804 | https://www.yageo.com/ | SMT | 15 | 上拉电阻
2 | C1,C2 | 2 | 100nF | 100nF 50V X7R 电容 | 0603 | Murata | GRM188R71H104KA93D | C14663 | LCSC | C14663 | https://www.murata.com/ | SMT | Samsung CL10B104KB8NNNC | 去耦电容
3 | U1 | 1 | STM32F103C8T6 | ARM Cortex-M3 主控 MCU | LQFP-48 | STMicroelectronics | STM32F103C8T6 | 15 | DigiKey | 497-6063-ND | https://www.st.com/ | SMT | 15 | 主控芯片
4 | J1 | 1 | USB-C | USB Type-C 母座 | USB-C-SMD | HRO | TYPE-C-31-M-12 | C165948 | LCSC | C165948 | 15 | SMT | 15 | 注意方向
5 | TP1 | 1 | TESTPOINT | 预留测试点 | TP-1mm | 15 | 15 | 15 | 15 | 15 | 15 | DNP | 15 | 默认不贴装

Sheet: 字段说明
字段 | 是否必填 | 填写说明
序号 | 必填 | 从 1 开始递增，方便评审和沟通。
位号 | 必填 | PCB 上的 Reference Designator，例如 R1,R2,R3。数量必须和位号个数一致。
数量 | 必填 | 该行物料数量。
参数/型号 | 必填 | 阻值、容值、芯片型号或连接器类型，例如 10k、100nF、STM32F103C8T6。
物料描述 | 必填 | 人能读懂的物料描述，建议写清关键规格。
封装 | 必填 | PCB 封装，例如 0603、SOT-23、LQFP-48。
品牌/制造商 | 建议 | 原厂或品牌名称。
原厂料号 | 建议 | Manufacturer Part Number，采购和替代料判断很重要。
LCSC编号 | 嘉立创贴片建议必填 | 嘉立创/LCSC 物料编号，例如 C25804。
供应商 | 建议 | 首选采购渠道，例如 LCSC、DigiKey、Mouser、淘宝。
供应商料号 | 建议 | 供应商 SKU 或订购编号。
数据手册 | 建议 | Datasheet 链接，或仓库内 datasheet 文件路径。
贴装方式 | 必填 | 填写 SMT、DIP、DNP、Mechanical、Manual 等。DNP 表示默认不贴装。
可替代料 | 建议 | 缺货时允许使用的替代型号。
备注 | 可选 | 极性、耐压、精度、方向、特殊装配要求等。

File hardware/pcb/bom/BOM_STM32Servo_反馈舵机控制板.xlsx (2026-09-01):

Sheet: BOM模板
序号 | 位号 | 数量 | 参数/型号 | 物料描述 | 封装 | 品牌/制造商 | 原厂料号 | LCSC编号 | 供应商 | 供应商料号 | 数据手册 | 贴装方式 | 可替代料 | 备注
1 | C1,C2,C3,C4,C5,C7,C13,C14,C15,C23,C24 | 11 | 100nF | 100nF | C0603 | SAMSUNG(三星) | CL10B104KB8NNNC | C1591 | LCSC | C1591 |  | SMT |  | 去耦电容
2 | C6 | 1 | 4.7uf | 4.7uf | C0603 | SAMSUNG(三星) | CL10A475KO8NNNC | C19666 | LCSC | C19666 |  | SMT |  | 主控电源滤波
3 | C8,C9,C17,C18,C19,C20 | 6 | 22uF | 22uF | C0603 | HRE(芯声) | CGA0603X5R226M100JT | C6119863 | LCSC | C6119863 |  | SMT |  | 电源滤波电容
4 | C10,C11 | 2 | 20pF | 20pF | C0603 | SAMSUNG(三星) | CL10C200JB8NNNC | C1648 | LCSC | C1648 |  | SMT |  | 晶振负载电容
5 | C21,C22 | 2 | 10uF | 10uF | C0603 | HRE(芯声) | CGA0603X5R106K100JT | C6119842 | LCSC | C6119842 |  | SMT |  | 电源滤波电容
6 | CN1,CN3 | 2 | SH1.0mm立式 | SH1.0mm立式 | CONN-SMD_2P-P1.00_HC-1.0-2PLT |  | SH1.0mm立式 | C9900005667 | LCSC | C9900005667 |  | SMT |  | 外接接口
7 | CN2,CN4 | 2 | SH-MX1.25-4PLT | SH-MX1.25-4PLT | CONN-SMD_4P-P1.25_SH-MX1.25-4PLT | SHOU HAN(首韩) | SH-MX1.25-4PLT | C53477387 | LCSC | C53477387 |  | SMT |  | 反馈舵机接口
8 | Cs | 1 | 50pF | 50pF | C0603 | CCTC(三环) | TCC0603COG500J500CT | C376792 | LCSC | C376792 |  | SMT |  | 触摸灵敏度电容
9 | FPC2 | 1 | FPC4_1mm(下接) | FPC4_1mm(下接) | FPC-SMD_4P-P1.00_C9900022405 |  | FPC4_1mm(下接) | C9900022405 | LCSC | C9900022405 |  | SMT |  | 灯板软排线
10 | H1,H3 | 2 | PZ254V-11-04P | PZ254V-11-04P | HDR-TH_4P-P2.54-V-M | XFCN(兴飞) | PZ254V-11-04P | C2691448 | LCSC | C2691448 |  | THT |  | 调试下载接口
11 | L1 | 1 | 1uH | 1uH | IND-SMD_L4.4-W4.2 | cjiang(长江微电) | FXL0420-1R0-M | C167203 | LCSC | C167203 |  | SMT |  | 升压电感
12 | LED1,LED3 | 2 | XL-1608UGC-04 | XL-1608UGC-04 | LED0603-RD_GREEN | XINGLIGHT(成兴光) | XL-1608UGC-04 | C965804 | LCSC | C965804 |  | SMT |  | 指示灯
13 | NRST-SW | 1 | 1TS002C-2300-4300-CT | 1TS002C-2300-4300-CT | SW-SMD_L6.0-W3.5-LS8.0-EH | HYP(鸿源精密) | 1TS002C-2300-4300-CT | C319340 | LCSC | C319340 |  | SMT |  | 复位按键
14 | Q2 | 1 | 2N7002 | 2N7002 | SOT-23-3_L2.9-W1.3-P1.90-LS2.4-BR | TWGMC(迪嘉) | 2N7002 | C727149 | LCSC | C727149 |  | SMT |  | 开关机控制
15 | R1,R3,R6,R8,R9,R10,R16 | 7 | 10K | 10K | R0603 | YAGEO(国巨) | RT0603BRD0710KL | C95204 | LCSC | C95204 |  | SMT |  | 上拉电阻
16 | R2,R12,R13,R14 | 4 | 0Ω | 0Ω | R0603 | UNI-ROYAL(厚声) | 0603WAF0000T5E | C21189 | LCSC | C21189 |  | SMT |  | 跳线电阻
17 | R4,R15 | 2 | 1kΩ | 1kΩ | R0402 | UNI-ROYAL(厚声) | 0402WGF1001TCE | C11702 | LCSC | C11702 |  | SMT |  | 限流电阻
18 | R5,R17 | 2 | 18K | 18K | R0603 | UNI-ROYAL(厚声) | 0603WAF1802T5E | C25810 | LCSC | C25810 |  | SMT |  | 反馈采样电阻
19 | R7 | 1 | 2Ω | 2Ω | R0603 | UNI-ROYAL(厚声) | 0603WAF200KT5E | C22977 | LCSC | C22977 |  | SMT |  | 电源限流电阻
20 | R11 | 1 | 100K | 100K | R0603 | YAGEO(国巨) | RT0603BRD07100KL | C122538 | LCSC | C122538 |  | SMT |  | 下拉电阻
21 | U1 | 1 | TTP223E-BA6 | TTP223E-BA6 | SOT-23-6_L2.9-W1.6-P0.95-LS2.8-BR | TONTEK(通泰) | TTP223E-BA6 | C129457 | LCSC | C129457 |  | SMT |  | 触摸芯片
22 | U2 | 1 | STM32F103CBT6 | STM32F103CBT6 | LQFP-48_L7.0-W7.0-P0.50-LS9.0-BL | ST(意法半导体) | STM32F103CBT6 | C8304 | LCSC | C8304 |  | SMT |  | 主控芯片
23 | U4 | 1 | ZX-SH1.0-3PLT | ZX-SH1.0-3PLT | CONN-SMD_3P-P1.00_HDGC_HDGC1002WV-S-3P | Megastar(兆星) | ZX-SH1.0-3PLT | C7430452 | LCSC | C7430452 |  | SMT |  | 电源端子
24 | U5 | 1 | IP5306 | IP5306 | ESOP-8_L4.9-W3.9-P1.27-LS6.0-BL-EP | INJOINIC(英集芯) | IP5306 | C181692 | LCSC | C181692 |  | SMT |  | 电源管理芯片
25 | U7 | 1 | PZ2.54-2*4 | PZ2.54-2*4 | HDR-TH_8P-P2.54-V-M-R2-C4-S2.54 | ZHOURI(洲日) | PZ2.54-2*4 | C5156676 | LCSC | C5156676 |  | SMT |  | Watcher通信接口
26 | U9 | 1 | YTC-TC6-268 | YTC-TC6-268 | TYPE-C-SMD_YIYUAN_YTC-TC6-268 | YIYUAN(怡远) | YTC-TC6-268 | C5260484 | LCSC | C5260484 |  | SMT |  | TYPE-C转接
27 | VBUS测试点 | 1 | Test-Point | Test-Point | Test-Point-0.5mm |  |  |  |  |  |  | DNP |  | 默认不贴装
28 | X2 | 1 | 8MHz | 8MHz | CRYSTAL-SMD_4P-L3.2-W2.5-BL | YXC(扬兴晶振) | X32258MOB4SI | C2682775 | LCSC | C2682775 |  | SMT |  | 外部高速晶振

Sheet: 填写示例
序号 | 位号 | 数量 | 参数/型号 | 物料描述 | 封装 | 品牌/制造商 | 原厂料号 | LCSC编号 | 供应商 | 供应商料号 | 数据手册 | 贴装方式 | 可替代料 | 备注
1 | R1,R2,R3 | 3 | 10k | 10k 1% 1/10W 电阻 | 0603 | YAGEO | RC0603FR-0710KL | C25804 | LCSC | C25804 | https://www.yageo.com/ | SMT | 15 | 上拉电阻
2 | C1,C2 | 2 | 100nF | 100nF 50V X7R 电容 | 0603 | Murata | GRM188R71H104KA93D | C14663 | LCSC | C14663 | https://www.murata.com/ | SMT | Samsung CL10B104KB8NNNC | 去耦电容
3 | U1 | 1 | STM32F103C8T6 | ARM Cortex-M3 主控 MCU | LQFP-48 | STMicroelectronics | STM32F103C8T6 | 15 | DigiKey | 497-6063-ND | https://www.st.com/ | SMT | 15 | 主控芯片
4 | J1 | 1 | USB-C | USB Type-C 母座 | USB-C-SMD | HRO | TYPE-C-31-M-12 | C165948 | LCSC | C165948 | 15 | SMT | 15 | 注意方向
5 | TP1 | 1 | TESTPOINT | 预留测试点 | TP-1mm | 15 | 15 | 15 | 15 | 15 | 15 | DNP | 15 | 默认不贴装

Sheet: 字段说明
字段 | 是否必填 | 填写说明
序号 | 必填 | 从 1 开始递增，方便评审和沟通。
位号 | 必填 | PCB 上的 Reference Designator，例如 R1,R2,R3。数量必须和位号个数一致。
数量 | 必填 | 该行物料数量。
参数/型号 | 必填 | 阻值、容值、芯片型号或连接器类型，例如 10k、100nF、STM32F103C8T6。
物料描述 | 必填 | 人能读懂的物料描述，建议写清关键规格。
封装 | 必填 | PCB 封装，例如 0603、SOT-23、LQFP-48。
品牌/制造商 | 建议 | 原厂或品牌名称。
原厂料号 | 建议 | Manufacturer Part Number，采购和替代料判断很重要。
LCSC编号 | 嘉立创贴片建议必填 | 嘉立创/LCSC 物料编号，例如 C25804。
供应商 | 建议 | 首选采购渠道，例如 LCSC、DigiKey、Mouser、淘宝。
供应商料号 | 建议 | 供应商 SKU 或订购编号。
数据手册 | 建议 | Datasheet 链接，或仓库内 datasheet 文件路径。
贴装方式 | 必填 | 填写 SMT、DIP、DNP、Mechanical、Manual 等。DNP 表示默认不贴装。
可替代料 | 建议 | 缺货时允许使用的替代型号。
备注 | 可选 | 极性、耐压、精度、方向、特殊装配要求等。

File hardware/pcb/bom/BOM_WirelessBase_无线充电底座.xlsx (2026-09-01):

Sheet: BOM模板
序号 | 位号 | 数量 | 参数/型号 | 物料描述 | 封装 | 品牌/制造商 | 原厂料号 | LCSC编号 | 供应商 | 供应商料号 | 数据手册 | 贴装方式 | 可替代料 | 备注
1 | LED6,LED7,LED8,LED9,LED10,LED11,LED12,LED13,LED14,LED15,LED16,LED17,LED18,LED19,LED20,LED21,LED22,LED23,LED24,LED25,LED26,LED27,LED28,LED29,LED30,LED31,LED32,LED33,LED34,LED35,LED36,LED37,LED38,LED39,LED40,LED41,LED42,LED43,LED44 | 39 | WS2812B-2020 | WS2812B-2020 | LED-SMD_4P-L2.0-W2.0-TL_WS2812B-2020 | worldsemi | WS2812B-2020 | C965555 | LCSC | C965555 |  | SMT |  | RGB灯珠
2 | R2,R3 | 2 | 5.1kΩ | 5.1kΩ | R0603_3 | UNI-ROYAL(厚声) | 0603WAF5101T5E | C23186 | LCSC | C23186 |  | SMT |  | Type-C CC电阻
3 | U1 | 1 | PR5L5015-3P-C-H | PR5L5015-3P-C-H | CONN-TH_PR5L5015-3P-C-H | SAMZO(三佐) | PR5L5015-3P-C-H | C41361291 | LCSC | C41361291 |  | THT |  | 磁吸pin口
4 | U3 | 1 | YTC-TC6-268 | YTC-TC6-268 | TYPE-C-SMD_YIYUAN_YTC-TC6-268 | YIYUAN(怡远) | YTC-TC6-268 | C5260484 | LCSC | C5260484 |  | SMT |  | TYPE-C供电

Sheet: 填写示例
序号 | 位号 | 数量 | 参数/型号 | 物料描述 | 封装 | 品牌/制造商 | 原厂料号 | LCSC编号 | 供应商 | 供应商料号 | 数据手册 | 贴装方式 | 可替代料 | 备注
1 | R1,R2,R3 | 3 | 10k | 10k 1% 1/10W 电阻 | 0603 | YAGEO | RC0603FR-0710KL | C25804 | LCSC | C25804 | https://www.yageo.com/ | SMT | 15 | 上拉电阻
2 | C1,C2 | 2 | 100nF | 100nF 50V X7R 电容 | 0603 | Murata | GRM188R71H104KA93D | C14663 | LCSC | C14663 | https://www.murata.com/ | SMT | Samsung CL10B104KB8NNNC | 去耦电容
3 | U1 | 1 | STM32F103C8T6 | ARM Cortex-M3 主控 MCU | LQFP-48 | STMicroelectronics | STM32F103C8T6 | 15 | DigiKey | 497-6063-ND | https://www.st.com/ | SMT | 15 | 主控芯片
4 | J1 | 1 | USB-C | USB Type-C 母座 | USB-C-SMD | HRO | TYPE-C-31-M-12 | C165948 | LCSC | C165948 | 15 | SMT | 15 | 注意方向
5 | TP1 | 1 | TESTPOINT | 预留测试点 | TP-1mm | 15 | 15 | 15 | 15 | 15 | 15 | DNP | 15 | 默认不贴装

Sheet: 字段说明
字段 | 是否必填 | 填写说明
序号 | 必填 | 从 1 开始递增，方便评审和沟通。
位号 | 必填 | PCB 上的 Reference Designator，例如 R1,R2,R3。数量必须和位号个数一致。
数量 | 必填 | 该行物料数量。
参数/型号 | 必填 | 阻值、容值、芯片型号或连接器类型，例如 10k、100nF、STM32F103C8T6。
物料描述 | 必填 | 人能读懂的物料描述，建议写清关键规格。
封装 | 必填 | PCB 封装，例如 0603、SOT-23、LQFP-48。
品牌/制造商 | 建议 | 原厂或品牌名称。
原厂料号 | 建议 | Manufacturer Part Number，采购和替代料判断很重要。
LCSC编号 | 嘉立创贴片建议必填 | 嘉立创/LCSC 物料编号，例如 C25804。
供应商 | 建议 | 首选采购渠道，例如 LCSC、DigiKey、Mouser、淘宝。
供应商料号 | 建议 | 供应商 SKU 或订购编号。
数据手册 | 建议 | Datasheet 链接，或仓库内 datasheet 文件路径。
贴装方式 | 必填 | 填写 SMT、DIP、DNP、Mechanical、Manual 等。DNP 表示默认不贴装。
可替代料 | 建议 | 缺货时允许使用的替代型号。
备注 | 可选 | 极性、耐压、精度、方向、特殊装配要求等。

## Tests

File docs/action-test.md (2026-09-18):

English | [简体中文](action-test_zh.md)

# First-run Check

Power on only after flashing and SD-card preparation, then run this minimum check:

1. The display reaches the normal interface without staying black or rebooting repeatedly.
2. Open Phone Control, wait a few seconds, and connect the phone over BLE.
3. Desktop or the App can discover and connect to the robot.
4. Play one expression and confirm the display, sound, and SD-card resources.
5. Run one small movement and confirm the STM32, servos, and lights.
6. When using the SDK, run `watcherobot robot status` and confirm that device status is returned.

If a step fails, record that step and the screen or script message, then return to the matching section of the [Flashing Guide](flashing.md).

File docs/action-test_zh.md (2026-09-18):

[English](action-test.md) | 简体中文

# 首次运行检查

完成烧录和 SD 卡准备后再上电，做一次最小检查：

1. 屏幕进入正常界面，没有停留在黑屏或反复重启。
2. 打开 Phone Control，等待几秒后用手机通过 BLE 连接机器人。
3. 桌面端或 App 能发现并连接机器人。
4. 播放一个表情，确认屏幕、声音和 SD 卡资源正常。
5. 执行一个小幅动作，确认 STM32、舵机和灯效正常。
6. 使用 SDK 时，运行 `watcherobot robot status`，确认能返回设备状态。

任一步失败时，先记录失败步骤和屏幕或脚本提示，再回到[烧录指南](flashing_zh.md)对应章节检查。

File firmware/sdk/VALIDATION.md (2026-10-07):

# Development-preview acceptance / 开发预览验收

No stable release or fully validated firmware pairing is claimed.
本页仅记录实际执行结果；构建成功不等于整机安全验证完成。

| Item / 项目 | Status / 状态 |
| --- | --- |
| Public body/head/robot builds | Windows IDF 6.0.2 passed / Windows 构建通过 |
| Separate developer project | Complete standalone flash and body command-chain HIL passed; details below / 独立完整烧录及身体命令链路测试通过，详见下文 |
| Windows/Linux remote CI | All jobs passed at `4d00c5d`; final integrated commit checks are recorded in [PR #6](https://github.com/orulink-ai/WatcheRobot-public/pull/6) / 最终整合版本 CI 以该 PR 的提交检查为准 |
| STM32 commit/version | Local patched `25d70f5a78c1`, dirty, FW 0.1.0, HW 1, capability `0x47`; original image was `0x45` / 当前为本地灯光声明补丁版本 |
| Himax PTL SHA256 | Not recorded / 未记录 |
| Hardware: motion, lights, body touch | Repeated motion/light/stop command chain passed on patched pairing; body touch and full acceptance pending / 补丁配对下重复运动、灯光、停止链路通过，身体触摸及完整验收待完成 |
| Hardware: JPEG, PCM, display | Partial results below; not full acceptance / 部分结果见下文，非完整验收 |

2026-10-06: ten Windows MSVC host projects passed in Debug and Release
(22 CTest executions, including UART concurrency tests). Public tool and SDK
contract pytest suite passed (63 tests after the display regression test, including Windows/Shell script parity). Builds
resolved dependencies in new project directories using the installed IDF and
local download cache; this is not a clean-machine installation claim.

2026-10-06 hardware smoke: a separate ESP-IDF project with its own `app_main`,
CMake and partition table consumed a GitHub clone of the public preview SDK,
with the audio/display fixes applied locally. Only the ESP32 application was
updated during these retests; STM32 and Himax were not flashed. No motor commands
were sent. Observed on ESP32-S3 rev 0.2, 8 MB PSRAM:

- LCD and SPD2010 touch driver initialization returned `ESP_OK`; physical screen
  rendering was confirmed by the operator; finger interaction still needs confirmation. Fix: prepare the
  shared IO expander and enable the LCD power rail before panel initialization.
- PTL single capture returned `ESP_OK`, JPEG 16,324 bytes with SOI/EOI markers.
  Full JPEG decoding, continuous streaming and restart remain unverified.
- PCM 16 kHz capture/play/close and two 24 kHz init/capture/play/close cycles
  returned `ESP_OK` without I2S errors. BSP-owned format configuration preserves
  its physical microphone slot and codec-open bookkeeping. These return values
  alone do not verify audible output, sample quality or long-term leak freedom.
- Body reached `ESP_ERR_NOT_SUPPORTED`: peer advertises motion, touch and power,
  but no LED capability. This failure did not prevent head modules from working.
  Do not bypass the gate or list this firmware as a fully compatible pairing.

The local pre-test backup covers the lower 16 MB only; boot logs report a 32 MB
physical flash. No full-chip backup or official-restoration acceptance is claimed.
Backups may contain device secrets and must never be published.

Release gates: clean-checkout setup and all builds; ordered events and observable
overflow; motion limits/stop/rejection/completion/fault; no reconnect replay; JPEG
decode and stream restart; PCM 16k/24k and volume; screen touch; concurrent lifecycle;
missing/incompatible hardware isolation; custom flashing and official restoration.
Record board revision, SDK commit, STM32 version, Himax checksum and evidence.

2026-10-06 follow-up (not full body acceptance): backed up the original STM32
128 KiB locally, then flashed the original `25d70f5a78c1` source with only
the three-line `APP_LED_ENABLE` capability-advertisement correction. OpenOCD
reported `Verified OK`. Test-image SHA256:
`ac385f806bf634b714c99c5219129f5141f469f2d0ffcd8494aedd7e4af217a0`.
This is a local patched baseline, not an unmodified released firmware pairing.
The same correction passed all five host suites on the current STM32 checkout.

The separate developer application was rebuilt with IDF 6.0.2 and app-flashed
successfully. It offers screen buttons for color changes, a manually initiated
fixed-target motion sequence (90/120 degrees over 3 s, then X=95/85/90 degrees
with Y=120), and stop. There are no explicit position queries; fixed timings
are not evidence of motion completion. The initial move may be larger than
5 degrees because the starting position is unknown. No automatic motor test
runs at boot, and no reconnect replay is implemented in the test application.
Physical lights, button touch, motion and stop still await operator confirmation.
Per the operator's request, no runtime feedback was read during this follow-up.

2026-10-07 runtime regression and automatic HIL:

- The operator confirmed one successful screen-driven color change and motion,
  then reported `Body not ready`. ESP32 logs confirmed later clicks reached the
  button handler but light submissions returned `ESP_ERR_INVALID_STATE`.
- The STM32 baseline disables periodic sensor reports. The SDK incorrectly
  treated five seconds of quiet as disconnection. A diagnostic UART reader can
  also cause a transient gate-contention error that latched the SDK in FAULT
  while the lower link stayed READY. Host regressions reproduced that failure
  before the correction; Debug and Release passed afterward, along with 15
  public SDK contract/script tests.
- The worker now takes the recursive UART gate before polling, skips transient
  contention, marks recoverable transport failures degraded for re-handshake,
  and probes quiet peers with HELLO without clearing READY. Missing responses
  still invalidate readiness; recovery does not resend movement. No position
  or sensor query is needed for liveness.
- A device carrying a different partition table failed to boot after an
  app-only update (`0x20000` device app versus `0x10000` example app). Complete
  example bootloader/partition/app flashing restored startup. Application-only
  flashing requires checking the connected device's layout.
- Two 55-second captures used ESP32 and the positively identified STM32 debug
  UART. In the final run, three light submissions each completed, fixed-target
  motion received ACK and successful completion, stopping the in-flight motion
  emitted `STOPPED` for its original sequence after 991 ms, and a second motion
  sequence completed. Every periodic health observation remained READY; no
  timeout or invalid-state rejection occurred. STM32 `servo_apply` logs confirm
  execution of the motion path. These are command/execution results, not ADC
  position verification. The first capture's stop-completion check lacked the
  needed application event log; the second captured it and all nine checks
  passed. This is not a long-duration or mechanical-limits acceptance claim.

Local independent test-app SHA256:
`95eec7390ca4d1d5afccb2c7d3eeab30f006fcedd8a7b11030a7c9d832e27451`.
The local test app adds serial commands and periodic health logs; these test
hooks are not part of the SDK API or the three public example entry points.

2026-10-07 pre-merge review corrections:

- SYS ACK/NACK now use the existing motion service's last-32-command sequence
  window. HELLO/LED replies no longer masquerade as motion events. Older replies
  outside this bounded window are ignored; typed DONE/FAULT remain unfiltered,
  preserving the original motion sequence when STOP completes an earlier move.
- Body lifecycle changes during event dispatch, and concurrent closes, are
  rejected with `ESP_ERR_INVALID_STATE`. A timed-out close remains retryable.
  The new host regressions failed before each fix and passed afterward.
- These final corrections have host/build coverage; the prior HIL application
  checksum refers to the earlier runtime correction, not this final source.

The ESP32 development branch advanced during delivery. Its display-owned DMA
staging improvements were retained during integration, and the public snapshot
uses the same display/BSP source. LCD release host tests now exercise SPI drain
and ISR-detach failures, ensure resources remain intact and the LVGL lock is
released, then retry successfully. Both LCD staging/release tests passed on
Windows; public CI also runs them on Windows/Linux in Debug/Release.

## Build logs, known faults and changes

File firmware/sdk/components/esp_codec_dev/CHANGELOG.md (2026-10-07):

# Changelog

## v1.2.0

### Features

- Add IDF v5.3 support  
  Using new i2c driver `esp_driver_i2c`, add `bus_handle` configuration for `audio_codec_i2c_cfg_t`.  
  User need create the `bus_handle` using API `i2c_new_master_bus` instead of `i2c_driver_install`.
- Change test code to standalone application, user can directly build it under folder [codec_dev_test](test_apps/codec_dev_test)

### Bug Fixes

- Fix I2S work in PDM mode record or play mono channel audio wrongly

## v1.1.0

### Features

- Add driver for AW88298, see detail datasheet [AW88298](https://datasheetspdf.com/download_new.php?id=1513778)

### Bug Fixes

- Fix ES8311 playback fade in for long time

## v1.0.3

### Bug Fixes

- Fix I2S TX and RX work in share mode, need enable TX before RX

## v1.0.2

### Features

- Add I2S TDM support
- Add API to `esp_codec_dev_set_in_channel_gain` to set input channel gain dependently

## v1.0.1

### Bug Fixes

- Fix ES8388 volume register set incorrectly

## v1.0.0

- Initial version of `esp_codec_dev`

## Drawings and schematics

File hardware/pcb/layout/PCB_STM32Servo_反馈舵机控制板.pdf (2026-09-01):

## CN1 H1

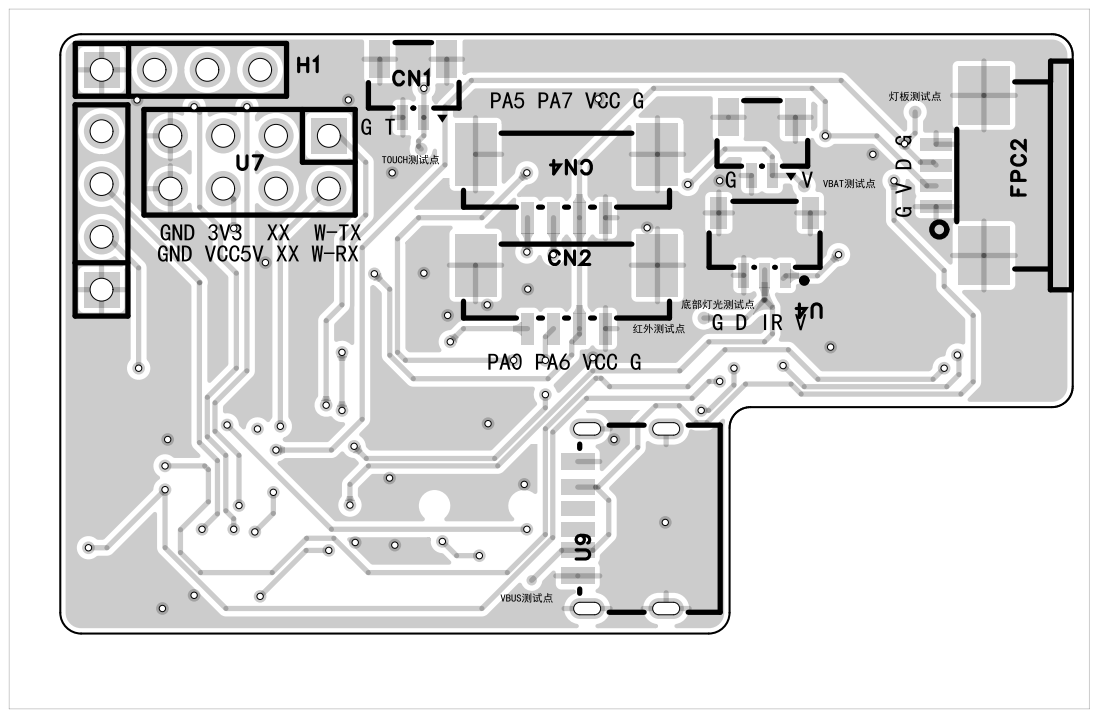
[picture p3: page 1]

R4

## LED3

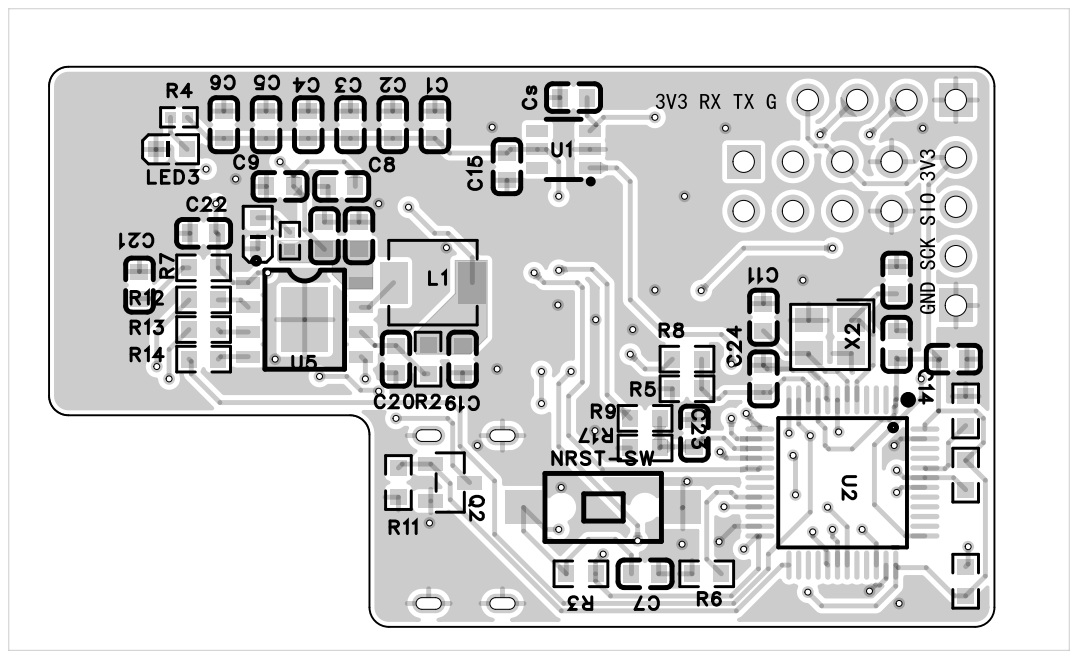
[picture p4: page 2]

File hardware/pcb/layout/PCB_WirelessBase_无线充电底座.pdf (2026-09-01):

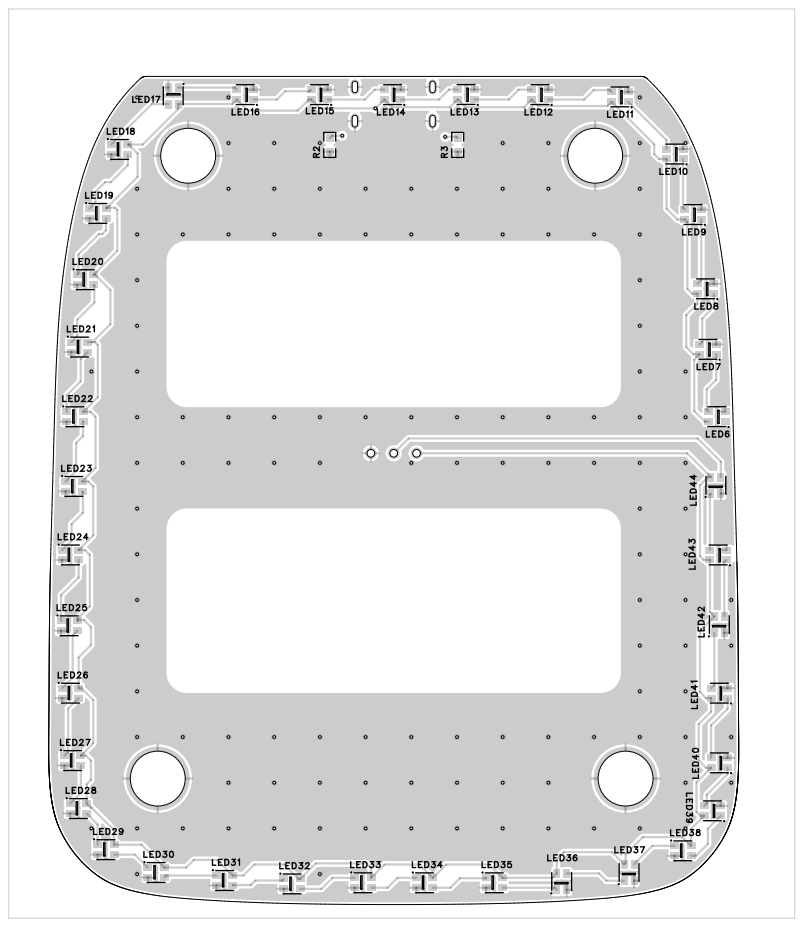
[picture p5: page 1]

LED6
LED38 LED39 LED⁴⁰ LED⁴¹ LED⁴² LED⁴³ LED⁴⁴

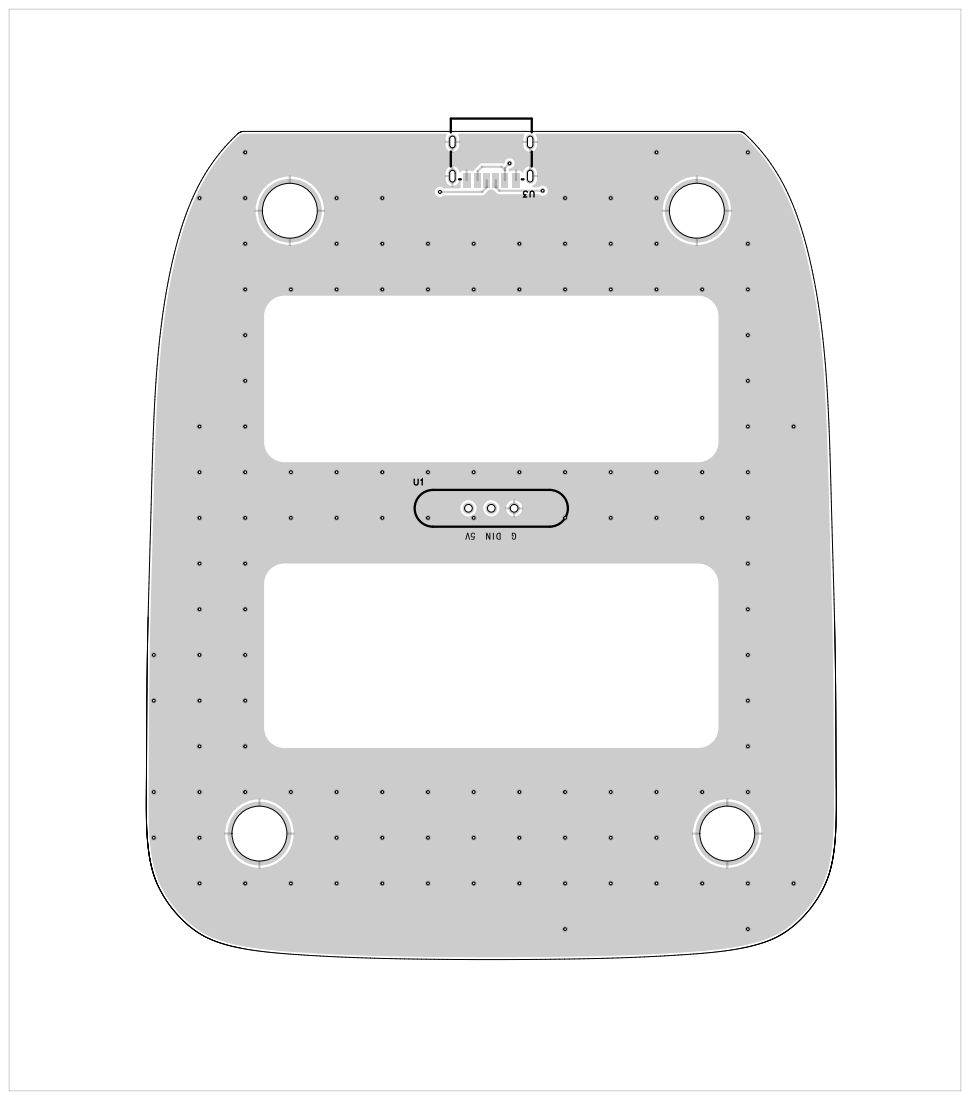
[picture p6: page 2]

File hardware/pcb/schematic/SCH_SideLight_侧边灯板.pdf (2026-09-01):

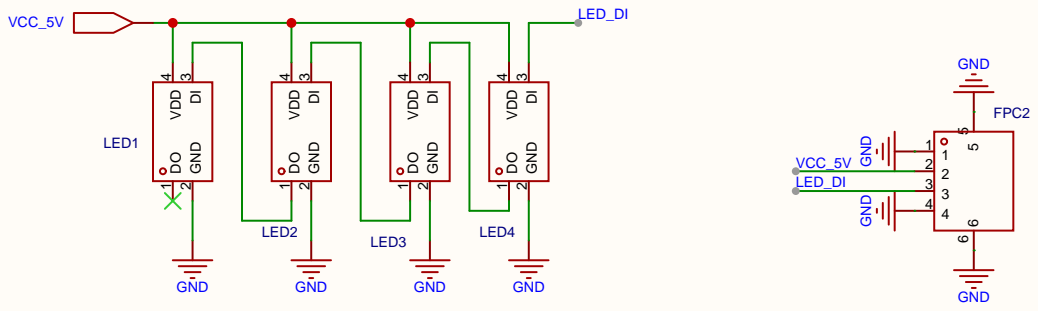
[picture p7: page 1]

原理图 | Schematic2 | 创建日期 | 2026-04-26

更新日期 | 2026-06-04

板子 | 侧边灯板 | 图页 | P1
绘制 | | WatcheRobot2.0
审阅

V1.0 | A4 | 嘉立创EDA

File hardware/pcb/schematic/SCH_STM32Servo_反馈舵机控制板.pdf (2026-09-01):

# 主控芯片

# 主控电源滤波电容

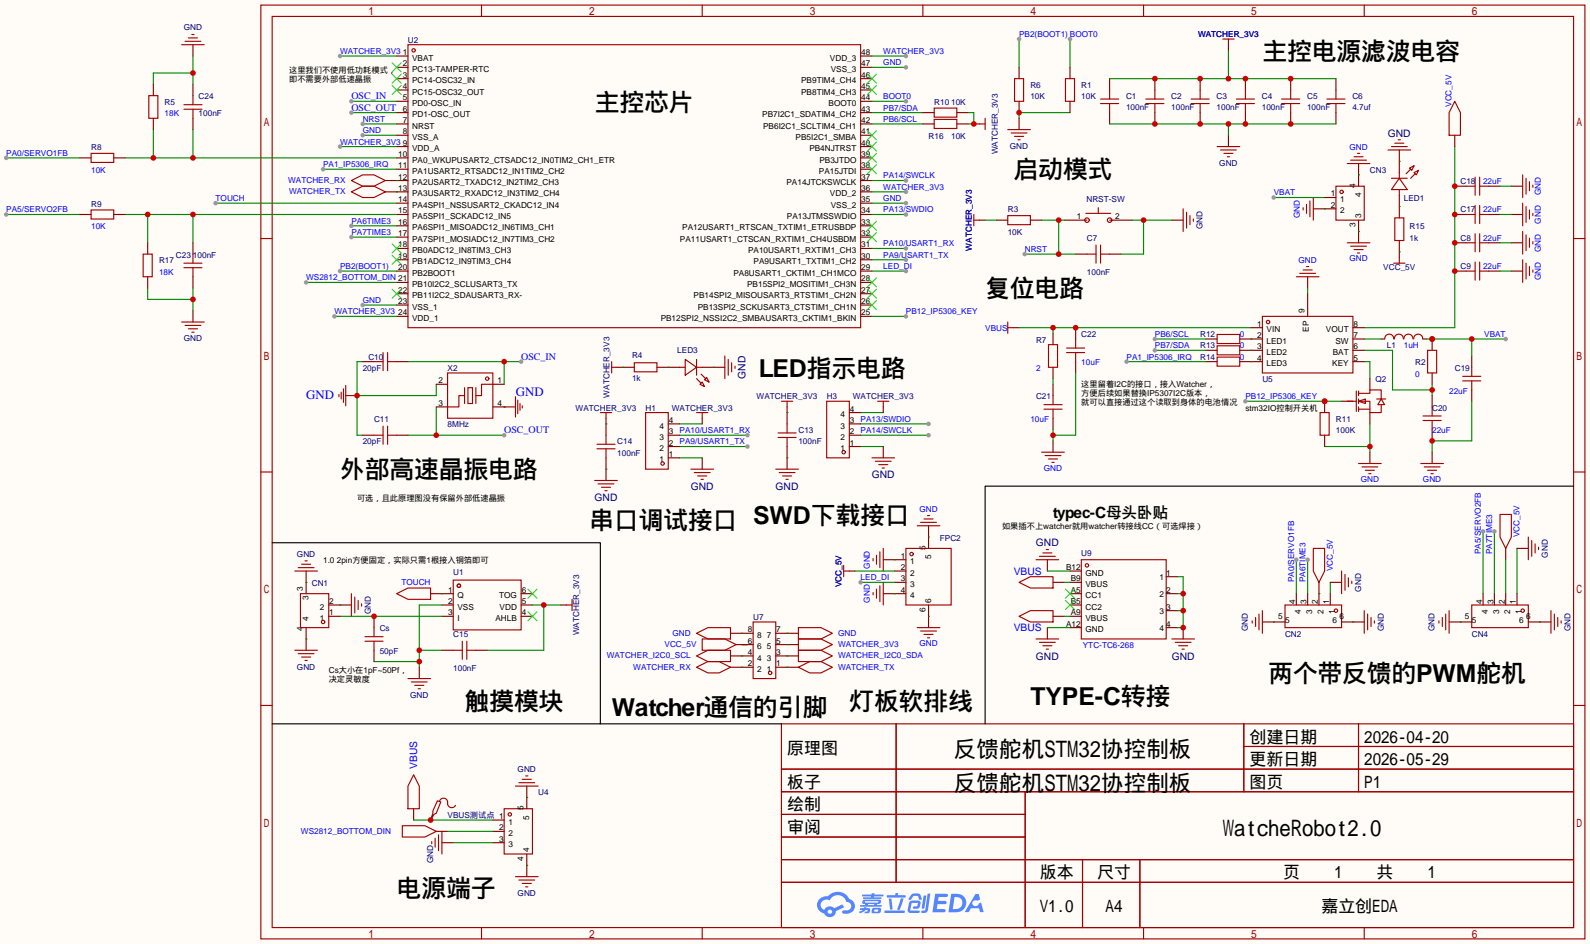
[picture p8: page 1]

GND GND

更新日期 | 2026-05-29

板子 | 反馈舵机STM32协控制板 | 图页 | P1
绘制 | | WatcheRobot2.0
审阅

V1.0 | A4 | 嘉立创EDA

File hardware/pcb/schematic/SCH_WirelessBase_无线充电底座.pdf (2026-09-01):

# LED9

# LED25

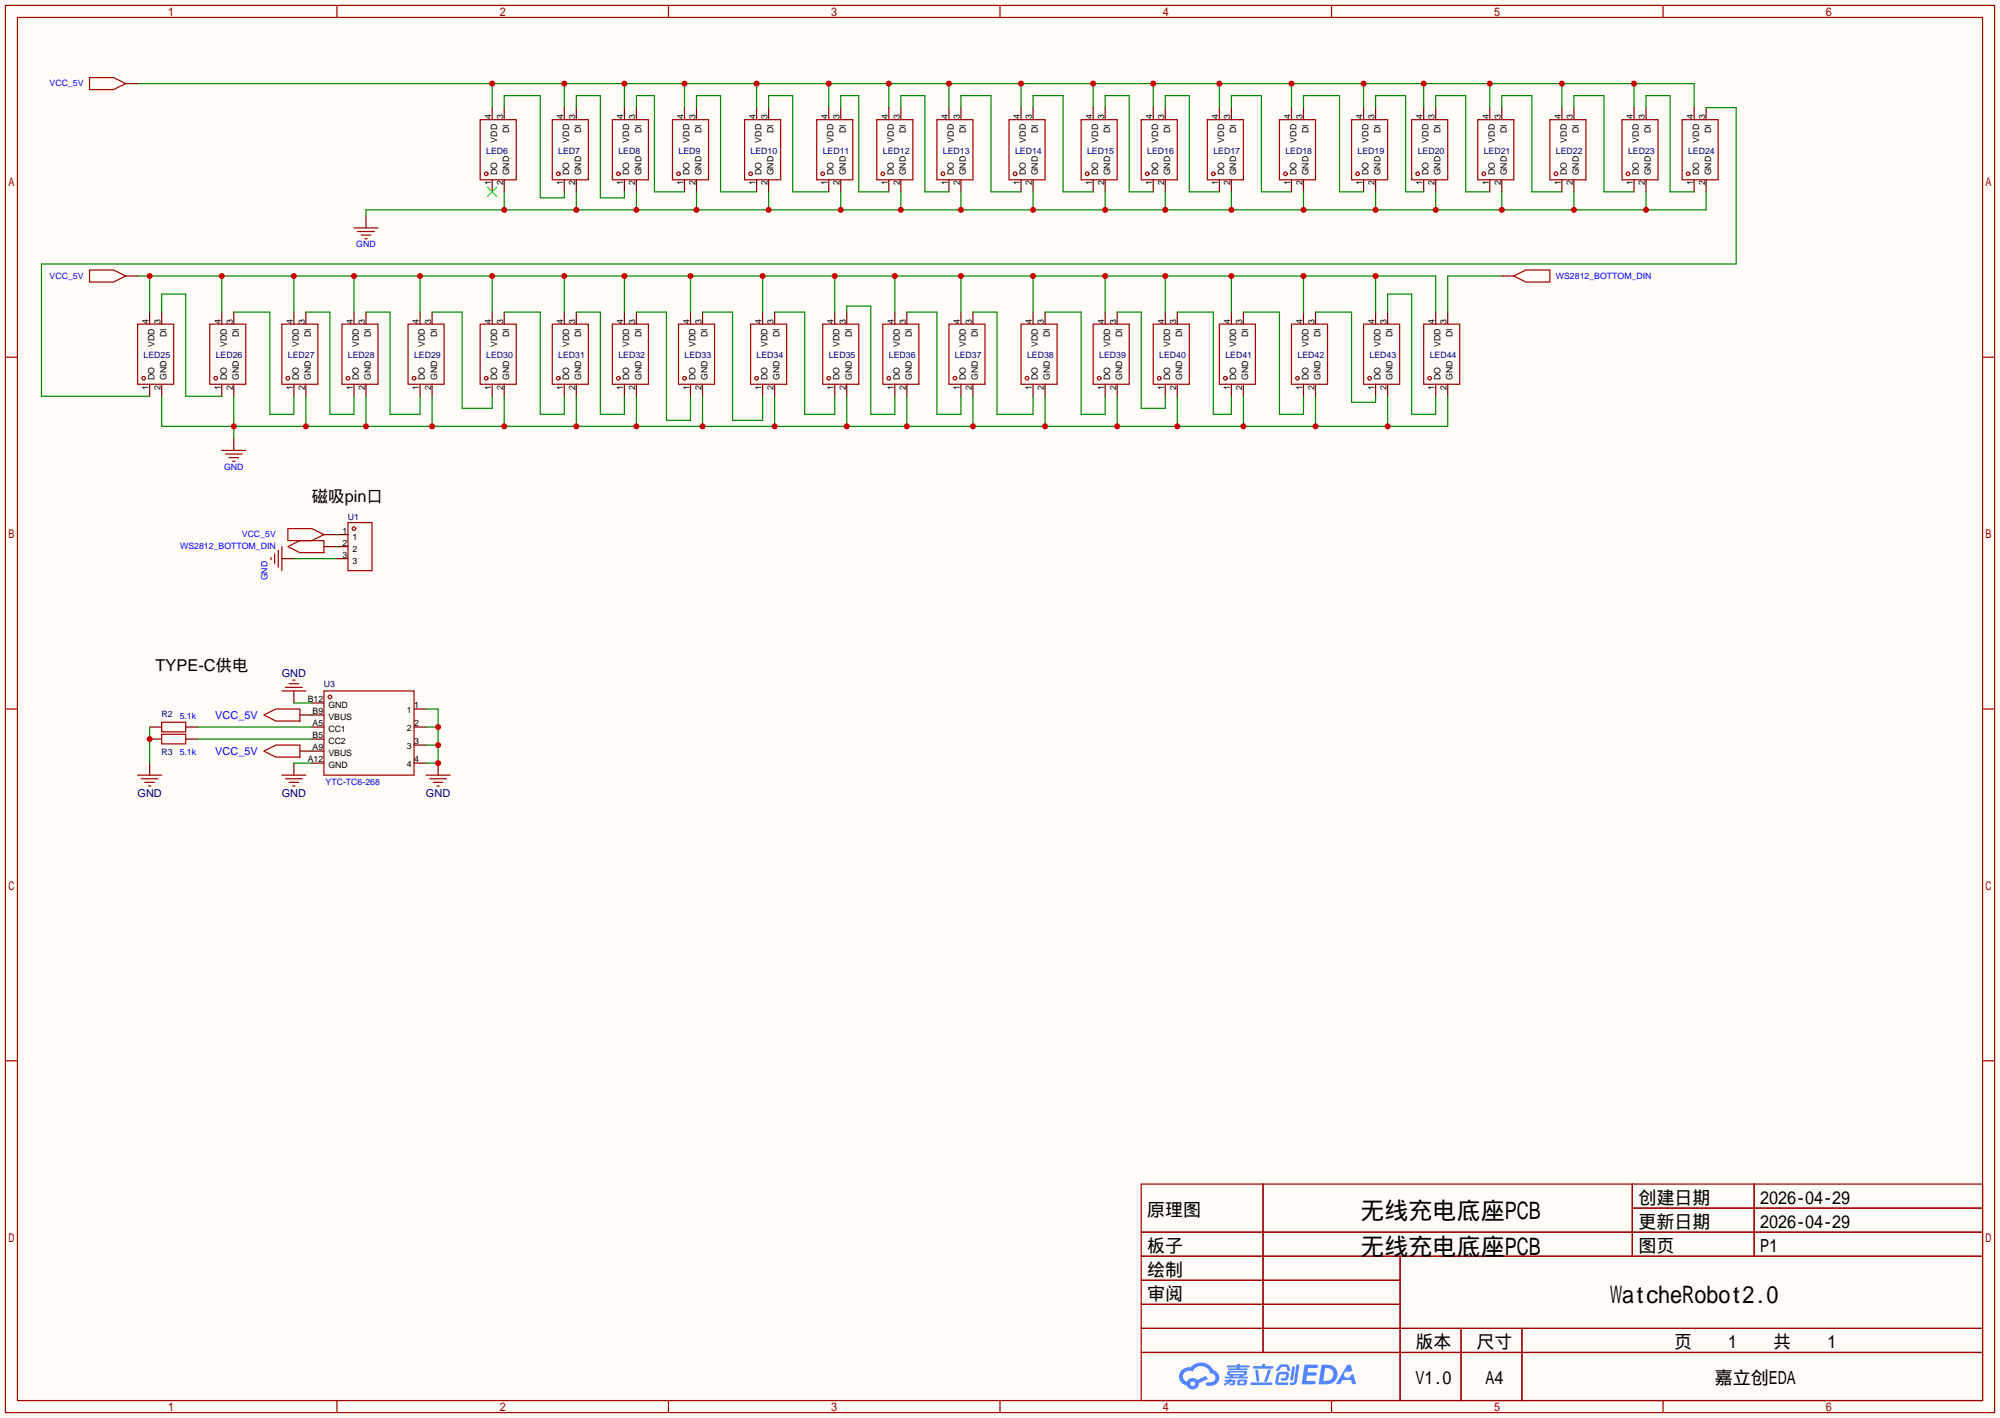
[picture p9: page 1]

原理图 | 无线充电底座PCB | 创建日期 | 2026-04-29
板子 | 无线充电底座PCB | 图页 | P1
绘制 | | WatcheRobot2.0
审阅

更新日期 | 2026-04-29

V1.0 | A4 | 嘉立创EDA

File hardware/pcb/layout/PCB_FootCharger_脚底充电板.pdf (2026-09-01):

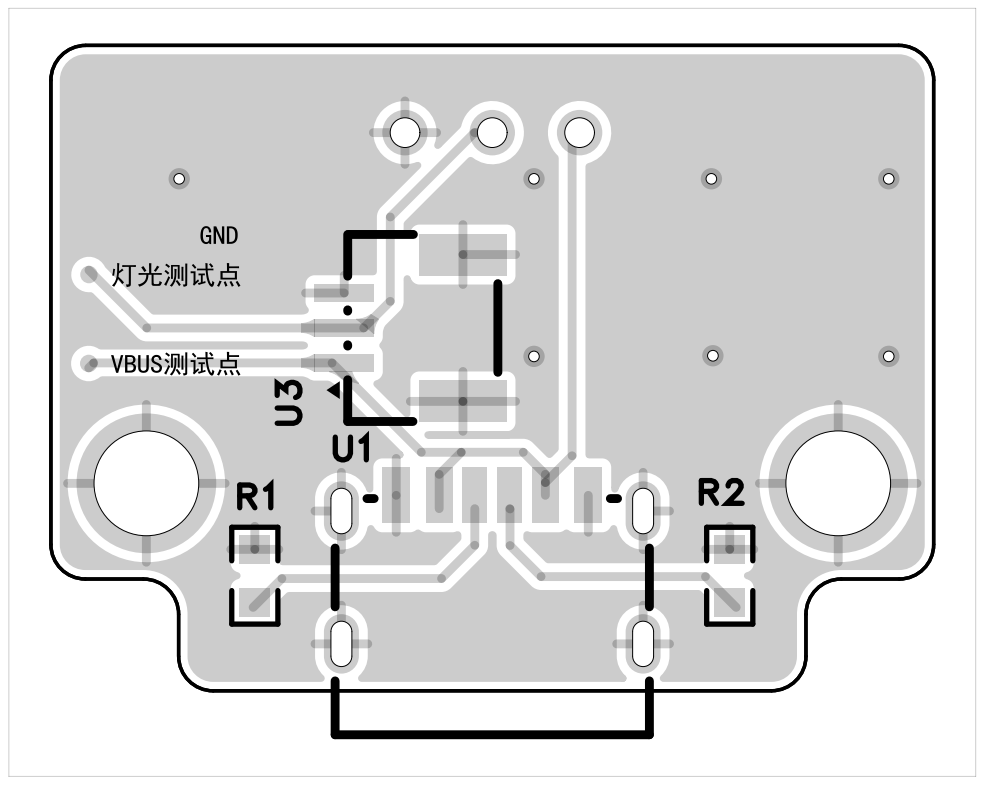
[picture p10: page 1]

U2 | N | S

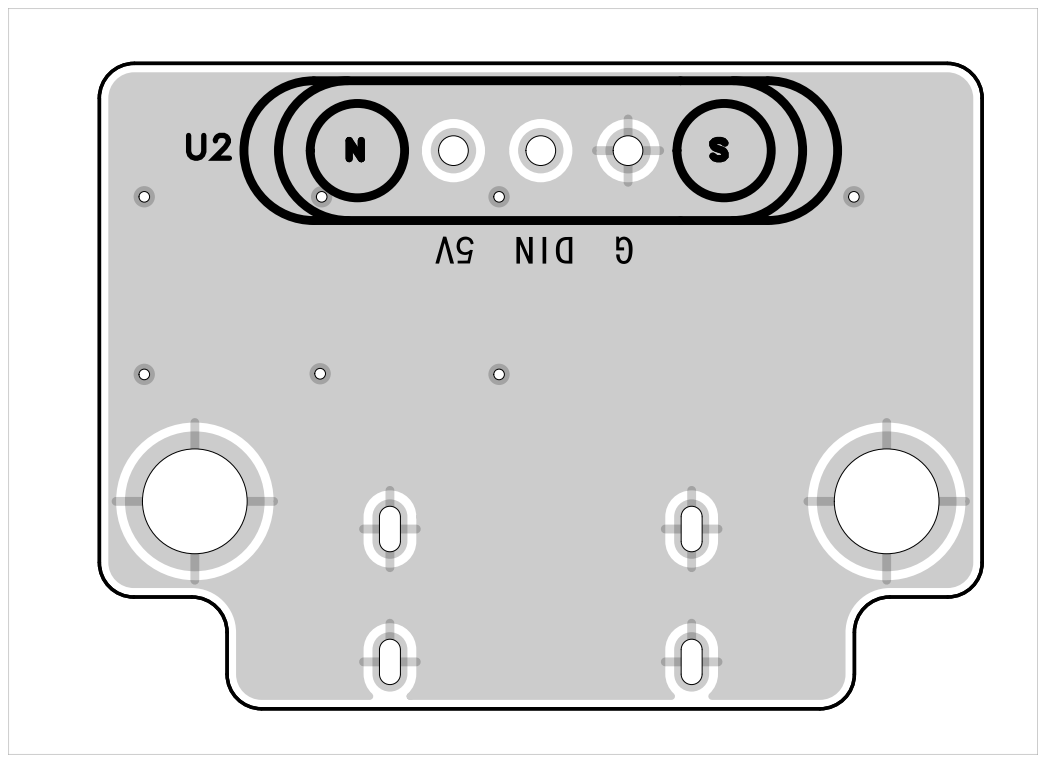
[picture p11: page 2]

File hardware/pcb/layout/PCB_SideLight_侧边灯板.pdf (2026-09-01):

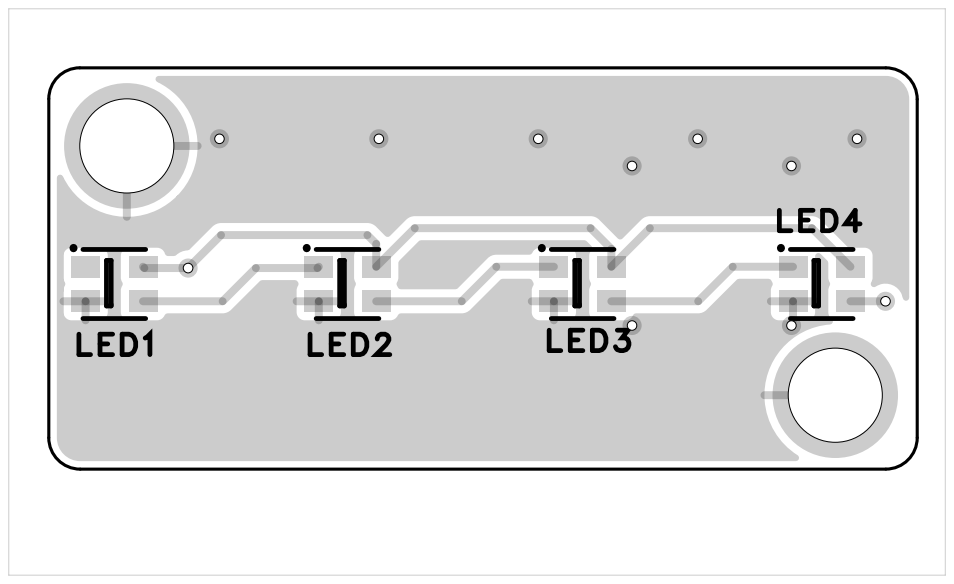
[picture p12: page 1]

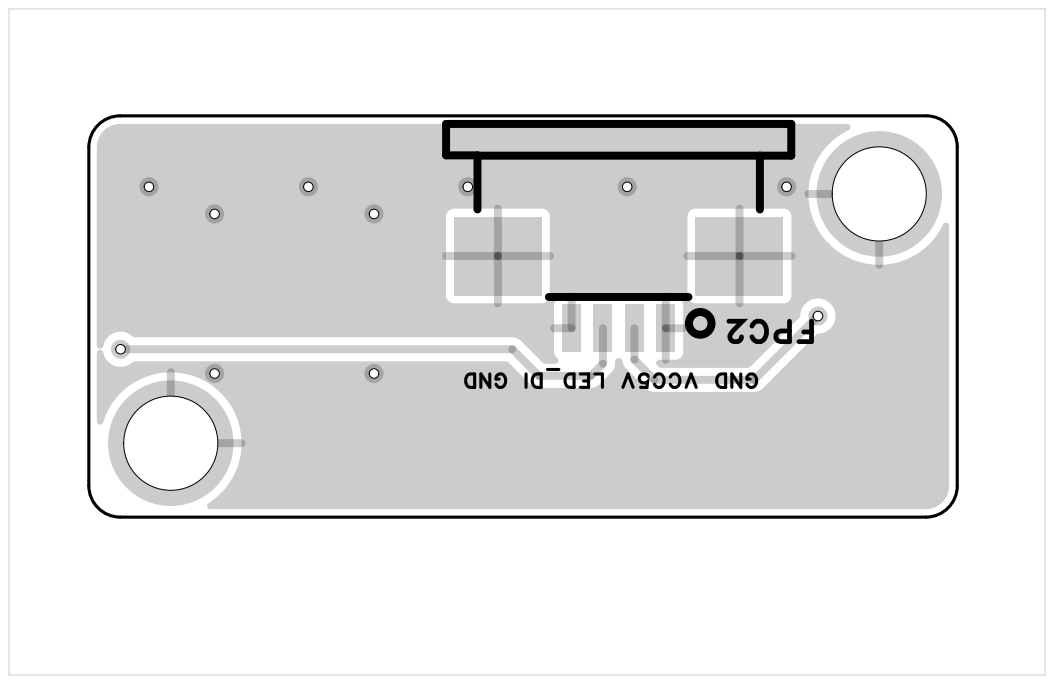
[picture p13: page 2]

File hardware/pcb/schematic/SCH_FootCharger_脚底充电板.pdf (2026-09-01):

# TYPE-C供电

## 无线充电接收磁吸pin

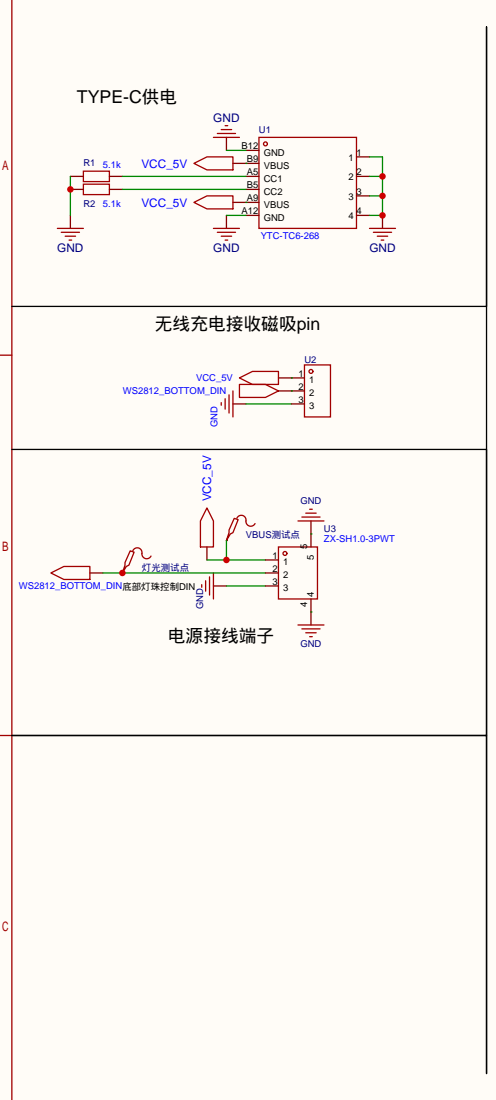
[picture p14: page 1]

原理图 | 脚底充电板原理图 | 创建日期 | 2026-04-27

更新日期 | 2026-06-10

板子 | 脚底充电板 | 图页 | P1
绘制 | | WatcheRobot2.0
审阅

V1.0 | A4 | 嘉立创EDA

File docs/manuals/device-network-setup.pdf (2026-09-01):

# 快速开始


1. 配置设备网络
如需使用桌面客户端或联网功能，请先为 WatcheRobot 配置 Wi‑Fi。
仅使用手机 App 的基础控制时，可跳过本步骤。

在 WatcheRobot 上操作 ⑤交互旋钮 或 ③触控屏 ，选择 Settings，进入 Wi‑Fi 设置页面。

Set up in App over Bluetooth

BLE MAC: 8C:BF:EA:8F:39:26

Open the app and select this BLE MAC to

configure Wi-Fi.

使用手机 App 配置 Wi‑Fi
打开 WatcheRobot App，点击“添加设备”，并选择与设备屏幕显示的设备唯一标识一致的
设备。按照 App 提示选择 Wi‑Fi 网络并输入密码，完成网络配置。

使用桌面客户端配置 Wi‑Fi
打开 WatcheRobot 桌面客户端，点击顶部的 “蓝牙设备配网”。选择与设备屏幕显示的设备
唯一标识一致的设备，按照客户端提示选择 Wi‑Fi 网络并输入密码，完成网络配置。

提示：由于产品固件及软件版本持续更新，实际界面可能与说明书截图存在差异，请以软件
实际显示为准。

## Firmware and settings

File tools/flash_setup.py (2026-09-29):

"""Prepare private flashing tools, then delegate to OpenOCD or the PTL package."""
import argparse
import hashlib
import json
import os
from pathlib import Path
import platform
import shutil
import subprocess
import sys
import tarfile
import urllib.request
import zipfile

CACHE = Path(__file__).resolve().parents[1] / '.local' / 'flash-runtime'


def check_environment():
    prefix = os.environ.get('CONDA_PREFIX')
    name = os.environ.get('CONDA_DEFAULT_ENV', '')
    if (not prefix or not name or name == 'base'
            or Path(prefix).resolve() != Path(sys.prefix).resolve()
            or not (Path(prefix) / 'conda-meta').is_dir()):
        raise RuntimeError('Create a dedicated environment: conda create -n watcherobot python=3.12 pip -y, then conda activate watcherobot. Do not use base.')
    if sys.version_info < (3, 12):
        raise RuntimeError('The flashing environment requires Python 3.12 or newer.')


def install_dependencies(requirements):
    check_environment()
    clean = os.environ.copy()
    for key in list(clean):
        if key.startswith('PIP_') or key in ('PYTHONPATH', 'PYTHONHOME', 'PYTHONUSERBASE'):
            clean.pop(key)
    clean['PIP_CONFIG_FILE'] = os.devnull
    clean['PYTHONNOUSERSITE'] = '1'
    run([sys.executable, '-I', '-m', 'pip', 'install', '--no-user', '--cache-dir', str(CACHE / 'pip-cache'), '-r', str(requirements)], env=clean)
OPENOCD = {
    ('Windows', 'x64'): ('win32-x64.zip', '6bfd3c97135aafef8affc9af1acf34fd0e2b9ca26044506f6abd7f95b7630052'),
    ('Darwin', 'arm64'): ('darwin-arm64.tar.gz', '667342c086984f3e5a55b4e0d5f711add13fb04de040fca493303000e6c19327'),
    ('Darwin', 'x64'): ('darwin-x64.tar.gz', '668ad25350103a4357e11629ec833eae5982e973889ce25bad0c2963e37fa8bf'),
    ('Linux', 'arm64'): ('linux-arm64.tar.gz', 'db73a3ab91c556ecec2405a7e02d404b11139df6aba1031cad94a7e6766d06cc'),
    ('Linux', 'x64'): ('linux-x64.tar.gz', '94b3790983beaf8ed57e646c0620dd66d705fddae03d290823a6ed3b439468d6'),
}


def run(command, **kwargs):
    print(subprocess.list2cmdline([str(x) for x in command]), flush=True)
    return subprocess.run(command, check=True, **kwargs)


def download(url, target, digest=None):
    target.parent.mkdir(parents=True, exist_ok=True)
    partial = target.with_suffix(target.suffix + '.partial')
    request = urllib.request.Request(url, headers={'User-Agent': 'WatcheRobot-flasher'})
    with urllib.request.urlopen(request, timeout=45) as source, partial.open('wb') as dest:
        shutil.copyfileobj(source, dest)
    if digest and hashlib.sha256(partial.read_bytes()).hexdigest() != digest:
        raise ValueError('Download integrity check failed: ' + target.name)
    partial.replace(target)


def extract(archive, destination):
    destination.mkdir(parents=True, exist_ok=True)
    if zipfile.is_zipfile(archive):
        with zipfile.ZipFile(archive) as bundle:
            for name in bundle.namelist():
                if not (destination / name).resolve().is_relative_to(destination.resolve()):
                    raise ValueError('Archive path escapes destination')
            bundle.extractall(destination)
    else:
        with tarfile.open(archive) as bundle:
            bundle.extractall(destination, filter='data')


def openocd():
    existing = shutil.which('openocd')
    if existing:
        return Path(existing)
    system = platform.system()
    arch = 'arm64' if platform.machine().lower() in ('arm64', 'aarch64') else 'x64'
    suffix, digest = OPENOCD[(system, arch)]
    name = 'xpack-openocd-0.12.0-7-' + suffix
    folder = CACHE / 'openocd'
    executable = folder / 'xpack-openocd-0.12.0-7' / 'bin' / ('openocd.exe' if system == 'Windows' else 'openocd')
    if not executable.exists():
        archive = CACHE / name
        download('https://github.com/xpack-dev-tools/openocd-xpack/releases/download/v0.12.0-7/' + name, archive, digest)
        extract(archive, folder)
    run([str(executable), '--version'])
    return executable


def windows_driver():
    if platform.system() != 'Windows':
        return
    query = "@(Get-PnpDevice -PresentOnly | Where-Object { $_.InstanceId -match 'VID_0483&PID_3748' } | Select-Object Status) | ConvertTo-Json -Compress"
    result = run(['powershell', '-NoProfile', '-Command', query], capture_output=True, text=True)
    devices = json.loads(result.stdout or '[]')
    if isinstance(devices, dict):
        devices = [devices]
    if not devices:
        raise RuntimeError('Connect ST-LINK V2 to USB before running STM32 flashing.')
    if len(devices) != 1:
        raise RuntimeError('Connect only the intended ST-LINK V2 before flashing.')
    if devices[0]['Status'] == 'OK':
        return
    print('Preparing the official ST-LINK Windows driver...', flush=True)
    archive = CACHE / 'stsw-link009.zip'
    try:
        download('https://www.st.com/resource/en/driver/stsw-link009.zip', archive)
    except OSError:
        print('ST download unavailable; trying the pinned ST Community attachment.', flush=True)
        download('https://community.st.com/topic/trackAttachment?file_uuid=6a4a63e8-6ed8-9a75-9771-2fb58d5226f3&redirect=1', archive,
                 'df015c7760f974e9da0f4c5a098d62c72157ea45cd0e80694eb47ab7ef28352b')
    folder = CACHE / 'stlink-driver'
    extract(archive, folder)
    infs = list(folder.rglob('stlink_dbg_winusb.inf'))
    if not infs:
        raise RuntimeError('The downloaded ST-LINK driver package contains no INF files.')
    for inf in infs:
        print('Windows may ask to trust STMicroelectronics device software. Review the system prompt; do not disable signature enforcement.', flush=True)
        run(['pnputil', '/add-driver', str(inf), '/install'])
    result = run(['powershell', '-NoProfile', '-Command', query], capture_output=True, text=True)
    devices = json.loads(result.stdout or '[]')
    if isinstance(devices, dict):
        devices = [devices]
    if len(devices) != 1 or devices[0]['Status'] != 'OK':
        raise RuntimeError('ST-LINK driver is not ready. Reconnect ST-LINK and retry; use an administrator terminal if driver installation was denied.')


def stm32(args):
    firmware = args.package.resolve() / 'watcheRobot_STM32.bin'
    if not firmware.is_file() or not firmware.stat().st_size:
        raise ValueError('Select the extracted folder containing watcheRobot_STM32.bin')
    tool = openocd()
    base = [str(tool), '-f', 'interface/stlink.cfg', '-f', 'target/stm32f1x.cfg']
    if args.prepare_only:
        run([*base, '-c', 'echo STM32_CONFIG_PARSE_OK; shutdown'])
        print('Tools ready. No device was accessed or flashed.')
        return
    windows_driver()
    # Fixed relative filename avoids Tcl injection from user-selected paths.
    try:
        run([*base, '-c', 'program watcheRobot_STM32.bin verify reset exit 0x08000000'], cwd=firmware.parent)
    except subprocess.CalledProcessError:
        print('STM32 was not verified. If OpenOCD cannot connect to the target, check board power and SIO/SWDIO, SCK/SWCLK, GND wiring. Disconnect power before changing wires; do not erase as a workaround.', file=sys.stderr)
        raise
    print('STM32 flash verified successfully.')


def available_serial_ports():
    from serial.tools import list_ports
    return list(list_ports.comports())


def print_head_port_mapping(ports=None):
    """Print the CH342 role-to-argument mapping used by the head flasher."""
    ports = available_serial_ports() if ports is None else ports
    head_ports = [port for port in ports if (port.vid, port.pid) == (0x1A86, 0x55D2)]
    if not head_ports:
        print('No Watcher CH342 head ports detected.')
        return
    print('Watcher head ports:')
    print('Device name                            Port                 Command argument')
    for port in sorted(head_ports, key=lambda item: (item.serial_number or '', item.description or '')):
        description = port.description or 'Unknown CH342 port'
        upper = description.upper()
        if 'SERIAL-B' in upper:
            argument = f'--port {port.device}'
        elif 'SERIAL-A' in upper:
            argument = f'--vision-port {port.device}'
        else:
            argument = 'unconfirmed role'
        print(f'{description:<38} {port.device:<20} {argument}')


def validate_head_port_roles(control_port, vision_port, ports=None):
    """Require SERIAL-B for ESP32 control and SERIAL-A for Himax vision."""
    ports = available_serial_ports() if ports is None else ports
    found = {port.device.casefold(): port for port in ports}
    control = found.get(control_port.casefold())
    vision = found.get(vision_port.casefold())
    if control is None or vision is None:
        raise ValueError('Both specified head ports must be connected.')
    if control_port.casefold() == vision_port.casefold():
        raise ValueError('Control and vision ports must be different.')
    if any((port.vid, port.pid) != (0x1A86, 0x55D2) for port in (control, vision)):
        raise ValueError('Head flashing supports only the Watcher CH342 USB pair.')
    if not control.serial_number or control.serial_number != vision.serial_number:
        raise ValueError('The two head ports must belong to the same CH342 device.')
    control_name = (control.description or '').upper()
    vision_name = (vision.description or '').upper()
    if 'SERIAL-A' in control_name and 'SERIAL-B' in vision_name:
        raise ValueError(
            f'Head ports are reversed. Use --port {vision.device} (SERIAL-B / ESP32) '
            f'--vision-port {control.device} (SERIAL-A / Himax).')
    if 'SERIAL-B' not in control_name or 'SERIAL-A' not in vision_name:
        raise ValueError(
            'Cannot confirm head port roles. --port must be SERIAL-B and '
            '--vision-port must be SERIAL-A; do not infer from COM numbers.')


def head(args):
    package = args.package.resolve()
    entry = package / 'tools' / 'ptl_release.py'
    requirements = package / 'requirements.txt'
    if not entry.is_file() or not requirements.is_file():
        raise ValueError('Select the extracted PTL-paired folder containing tools and requirements.txt')
    install_dependencies(requirements)
    python = sys.executable
    run([str(python), str(entry), 'verify', '--bundle', str(package)])
    if args.prepare_only:
        print('Tools ready. No device was accessed or flashed.')
        return
    if not args.port or not args.vision_port:
        print_head_port_mapping()
        if not args.port and not args.vision_port:
            print('No firmware written. Run again with the SERIAL-B and SERIAL-A arguments shown above.')
            return
        raise ValueError('Specify --port (SERIAL-B) and --vision-port (SERIAL-A) from the same CH342 device.')
    validate_head_port_roles(args.port, args.vision_port)
    command = [str(python), str(Path(__file__).with_name('flash_head.py')), '--bundle', str(package),
               '--port', args.port, '--vision-port', args.vision_port]
    if getattr(args, 'factory', False):
        command.append('--factory')
    run(command)
    print('Head flash completed successfully: Himax and ESP32-S3.')


def sd_card(args):
    installer = Path(__file__).with_name('install_sd_card_resources.py')
    if args.prepare_only:
        run([sys.executable, str(installer), '--help'])
        print('SD-card writer ready. No card was accessed or changed.')
        return
    if not args.drive:
        raise ValueError('Specify the SD-card root with --drive, for example --drive E:\\\\ on Windows.')
    command = [sys.executable, str(installer), '--drive', str(args.drive)]
    if args.package:
        if not args.package.is_file():
            raise ValueError('Select the downloaded watche-sd-resources-*.tar.gz file.')
        command.extend(['--file', str(args.package.resolve())])
    if args.force:
        command.append('--force')
    run(command)


def sd_format(args):
    formatter = Path(__file__).with_name('format_sd_card.py')
    if args.prepare_only:
        run([sys.executable, str(formatter), '--help'])
        print('SD-card formatter ready. No card was accessed or changed.')
        return
    if not args.drive:
        raise ValueError('Specify the removable SD-card root with --drive, for example --drive F:\\ on Windows.')
    run([sys.executable, str(formatter), '--drive', str(args.drive)])


def main():
    parser = argparse.ArgumentParser(description=__doc__)
    parser.add_argument('target', choices=['stm32', 'head', 'sd-format', 'sd'])
    parser.add_argument('--package', type=Path,
                        help='Firmware directory, or an optional local SD resource tar.gz')
    parser.add_argument('--drive', type=Path, help='SD-card root, for example E:\\ or /Volumes/WATCHE')
    parser.add_argument('--port')
    parser.add_argument('--vision-port')
    parser.add_argument('--factory', action='store_true',
                        help='Head only: replace all ESP32 flash segments, including storage')
    parser.add_argument('--force', action='store_true',
                        help='SD only: discard an unfinished device-side SD transaction')
    parser.add_argument('--prepare-only', action='store_true', help='Prepare tools without accessing hardware')
    args = parser.parse_args()
    try:
        check_environment()
        if args.target in ('stm32', 'head') and args.package is None:
            raise ValueError('--package is required for firmware flashing.')
        if args.factory and args.target != 'head':
            raise ValueError('--factory is valid only for head flashing.')
        if args.force and args.target != 'sd':
            raise ValueError('--force is valid only for SD-card writing.')
        {'stm32': stm32, 'head': head, 'sd-format': sd_format, 'sd': sd_card}[args.target](args)
        return 0
    except (OSError, ValueError, KeyError, RuntimeError, subprocess.CalledProcessError) as exc:
        print('Flashing stopped: ' + str(exc), file=sys.stderr)
        return 1


if __name__ == '__main__':
    sys.exit(main())

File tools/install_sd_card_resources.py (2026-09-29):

#!/usr/bin/env python3
"""Install a versioned official resource archive through an SD-card reader."""

from __future__ import annotations

import argparse
import ctypes
import hashlib
import json
import os
import plistlib
import re
import shutil
import subprocess
import sys
import tarfile
import tempfile
from dataclasses import dataclass
from datetime import datetime, timezone
from pathlib import Path, PurePosixPath
from typing import Any

try:
    from .sd_package import InstallError, Package, VERSION_PATTERN, acquire_package
except ImportError:
    from sd_package import InstallError, Package, VERSION_PATTERN, acquire_package


ALLOWED_ROOTS = {"assets"}
ALLOWED_ROOT_FILES = {
    "official_catalog.json",
    "fixed_states.json",
    "resource_manifest.json",
}
LEGACY_ROOT_ENTRIES = {
    "anim",
    "actions",
    "sfx",
    "behavior",
    "resource_catalog.json",
    "resource_manifest.json",
}
MAX_ARCHIVE_BYTES = 64 * 1024 * 1024
MAX_EXTRACTED_BYTES = 96 * 1024 * 1024
MAX_SINGLE_FILE_BYTES = 16 * 1024 * 1024
MAX_FILES = 512
SPACE_RESERVE_BYTES = 4 * 1024 * 1024
SUPPORTED_FILESYSTEMS = {"FAT32"}
REQUIRED_ALLOCATION_UNIT_BYTES = 512
READER_TRANSACTION_NAME = "reader_transaction.json"
FIXED_STATES = {
    "boot",
    "standby",
    "listening",
    "thinking",
    "speaking",
    "processing",
    "error",
    "upgrade",
}
ASSET_LAYOUT = {
    "animation": ("anim", "anim", ".animpack", "animpack-v2"),
    "action": ("action", "actions", ".json", "firmware-action-json-v1"),
    "sound": ("sfx", "sfx", ".pcm", "pcm-s16le-24khz-mono"),
}


@dataclass(frozen=True)
class DriveInfo:
    root: Path
    label: str
    filesystem: str
    free_bytes: int
    total_bytes: int
    kind: str
    allocation_unit_bytes: int = 4096


@dataclass(frozen=True)
class ArchivePlan:
    version: str
    file_count: int
    extracted_bytes: int
    manifest: dict[str, Any]
    manifest_sha256: str


@dataclass(frozen=True)
class InstallResult:
    version: str
    file_count: int
    extracted_bytes: int
    skipped: bool = False


def parse_arguments(argv: list[str]) -> argparse.Namespace:
    parser = argparse.ArgumentParser(
        prog="tools/flash sd",
        description="Install an official resource package through an SD-card reader.",
    )
    parser.add_argument("version", nargs="?", help="Optional exact version in vX.Y.Z form; latest is the default.")
    parser.add_argument("--drive", type=Path, help=r"Explicit SD-card root, for example E:\.")
    parser.add_argument("--file", type=Path, dest="local_file", help="Explicit local tar.gz package for offline use.")
    parser.add_argument(
        "--force",
        action="store_true",
        help="Discard an unfinished device-side transaction before installing through the reader.",
    )
    arguments = parser.parse_args(argv)
    if arguments.version and not VERSION_PATTERN.fullmatch(arguments.version):
        parser.error("version must use the vMAJOR.MINOR.PATCH format")
    return arguments


def _windows_volume(root: str) -> tuple[str, str]:
    volume_name = ctypes.create_unicode_buffer(261)
    filesystem_name = ctypes.create_unicode_buffer(261)
    ok = ctypes.windll.kernel32.GetVolumeInformationW(
        ctypes.c_wchar_p(root),
        volume_name,
        len(volume_name),
        None,
        None,
        None,
        filesystem_name,
        len(filesystem_name),
    )
    if not ok:
        return "", ""
    return volume_name.value, filesystem_name.value.upper()


def _normalize_filesystem(value: str) -> str:
    compact = value.upper().replace("-", "").replace("_", "").replace(" ", "")
    return "FAT32" if compact in {"FAT32", "VFAT", "MSDOSFAT32", "MSDOS"} else value.upper()


def _posix_volume(root: Path) -> tuple[str, str, Path]:
    if sys.platform == "darwin":
        result = subprocess.run(
            ["diskutil", "info", "-plist", str(root)],
            check=True,
            capture_output=True,
        )
        info = plistlib.loads(result.stdout)
        mount = Path(str(info.get("MountPoint", ""))).resolve()
        label = str(info.get("VolumeName", ""))
        filesystem = str(info.get("FileSystemPersonality") or info.get("FilesystemType") or "")
        return label, _normalize_filesystem(filesystem), mount
    target = subprocess.run(
        ["findmnt", "-no", "TARGET", "-T", str(root)],
        check=True,
        capture_output=True,
        text=True,
    ).stdout.strip()
    filesystem = subprocess.run(
        ["findmnt", "-no", "FSTYPE", "-T", str(root)],
        check=True,
        capture_output=True,
        text=True,
    ).stdout.strip()
    label = subprocess.run(
        ["findmnt", "-no", "LABEL", "-T", str(root)],
        check=True,
        capture_output=True,
        text=True,
    ).stdout.strip()
    return label, _normalize_filesystem(filesystem), Path(target).resolve()


def _drive_info(root: Path, kind: str) -> DriveInfo:
    usage = shutil.disk_usage(root)
    label = ""
    filesystem = ""
    allocation_unit_bytes = 4096
    if os.name == "nt":
        label, filesystem = _windows_volume(str(root))
        sectors_per_cluster = ctypes.c_ulong()
        bytes_per_sector = ctypes.c_ulong()
        free_clusters = ctypes.c_ulong()
        total_clusters = ctypes.c_ulong()
        if ctypes.windll.kernel32.GetDiskFreeSpaceW(
            ctypes.c_wchar_p(str(root)),
            ctypes.byref(sectors_per_cluster),
            ctypes.byref(bytes_per_sector),
            ctypes.byref(free_clusters),
            ctypes.byref(total_clusters),
        ):
            allocation_unit_bytes = max(1, sectors_per_cluster.value * bytes_per_sector.value)
        else:
            raise OSError("Unable to read the SD-card allocation unit size.")
    else:
        label, filesystem, _mount = _posix_volume(root)
        allocation_unit_bytes = max(1, os.statvfs(root).f_frsize)
    return DriveInfo(root, label, filesystem, usage.free, usage.total, kind, allocation_unit_bytes)


def detect_removable_drives() -> list[DriveInfo]:
    if os.name != "nt":
        return []
    mask = ctypes.windll.kernel32.GetLogicalDrives()
    drives: list[DriveInfo] = []
    for index in range(26):
        if not mask & (1 << index):
            continue
        root_text = f"{chr(ord('A') + index)}:\\"
        if ctypes.windll.kernel32.GetDriveTypeW(root_text) != 2:
            continue
        root = Path(root_text)
        try:
            drives.append(_drive_info(root, "removable"))
        except OSError:
            continue
    return drives


def _normalize_explicit_drive(value: Path) -> Path:
    if os.name != "nt":
        return value.resolve()
    text = str(value).strip().replace("/", "\\")
    if not re.fullmatch(r"[A-Za-z]:\\?", text):
        raise InstallError(r"--drive must be a drive root such as E:\.")
    return Path(text[:2].upper() + "\\")
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

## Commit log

2026-09-01 初始化无历史公开仓库
    [BOM_FootCharger_脚底充电板.xlsx, BOM_STM32Servo_反馈舵机控制板.xlsx, BOM_SideLight_侧边灯板.xlsx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]
2026-09-08 docs: update STM32 board wiring photo
2026-09-08 docs: replace STM32 wiring photos with combined diagram
2026-09-18 feat: 增加安全的SD写卡流程并修正头部烧录校验
    新增中英文 SD 写卡 Skill、Windows/macOS/Linux 统一命令、官方资源自动下载、FAT32 与挂载点检查、逐文件校验及 watche 目录安装。同步修正文档中的 SD 卡结构和操作方式。
    头部烧录增加 CH342 SERIAL-A/B 角色校验与显式工厂恢复参数，避免端口填反及普通烧录无法修复分区表时误判成功。补充相关单元测试。
    [flash_setup.py, install_sd_card_resources.py, sd_package.py]
2026-09-18 docs: 完善整机烧录与验收指引
2026-09-18 fix: 保证SD写卡失败时保留旧资源
2026-09-29 功能：固定头部双芯片烧录顺序并同步中英文指引
2026-09-29 调整：SD卡格式化取消交互确认并保留文档提示
2026-09-29 修复：限制烧录阶段超时并补充失败路径验证
2026-10-06 feat(固件SDK): 公开独立硬件组件与三个ESP-IDF开发预览工程
    在firmware/sdk交付模块化watche_hw接口、共享MCU运行层与必要BSP/HAL依赖，保留Apache及第三方许可证。身体、头部和整机示例独立构建，固定ESP-IDF 6.0.2与依赖锁文件；提供语义一致的PowerShell/Shell入口。
    补充双语入门、公开范围与烧录边界文档，加入Windows/Linux主机测试和三示例CI。Windows三个示例及独立消费工程构建通过，十组主机工程Debug/Release共22次CTest通过，62项工具测试通过。尚未完成整机实机验收与固件配对版本登记，不声明稳定版。开发源码对应内部ESP32基线c8137bef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
    [partitions.csv]
2026-10-06 fix(固件SDK): 修复Linux主机编译的NULL声明依赖
    远程Linux失败日志确认MCU状态机隐式依赖Windows头文件。显式引入stddef.h，并关闭CI矩阵fail-fast，保留其他平台独立验收证据。相同源码修复已回流内部ESP32工作区。
2026-10-06 fix(firmware-sdk): 修复独立固件音频配置与屏幕供电初始化
    音频格式配置委托给 BSP，保留麦克风物理声道及 codec 打开状态；补充租约配置失败测试，禁止 SDK 直接重开 codec。
    屏幕初始化先准备共享 IO 扩展器与 LCD 电源，避免独立工程触摸初始化失败；增加初始化顺序回归测试。
    记录独立开发者工程的 ESP32 实机结果：JPEG 取帧、16k/24k PCM 录放及屏幕驱动初始化通过；明确 STM32 缺少 LED 能力仍阻止身体就绪，未发送电机指令，不宣称完整配对或正式发布。
2026-10-06 docs(sdk): 更新独立固件实机进展与手动控制验收边界
    记录音频及显示修复版本的跨平台 CI 通过结果和用户确认的屏幕显示。说明 STM32 原版本灯光能力声明补丁、烧录校验与测试镜像哈希；记录独立 ESP32 项目的手动灯光、固定目标运动及停止按钮，不主动查询位置反馈，物理验收仍待用户确认。
2026-10-07 fix(sdk): 修复安静固件误断线与串口竞争导致身体永久未就绪
    身体运行层在持有递归 UART 门禁后轮询，避免诊断读者的短暂竞争被当成通信故障；真正的轮询错误进入降级并重新握手。通信安静时使用不清除 READY 的 HELLO 探测，兼容关闭周期传感器上报的 STM32，不依赖舵机位置反馈。
    新增先失败后通过的主机回归，覆盖门禁竞争、可恢复传输错误及安静链路探测；保留超时拒绝控制和重连不重放运动。Windows Debug/Release 测试与 63 项公开工具测试通过。独立 IDF 6.0.2 固件完整烧录后同步采集两端日志，连续灯光、运动、停止及再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
2026-10-07 fix(sdk): 完善运动事件关联与关闭门禁并同步源码规范
    审查发现通用 ACK/NACK 可能误报运动事件、事件分发期间关闭可能失效借用上下文。在既有运动服务使用有界32命令序列窗口，保留typed DONE/FAULT原序列；身体模块拒绝分发期间初始化/关闭及并发关闭，保留超时重试。
    TDD：两项主机回归修复前失败、修复后通过。63项工具/接口/脚本测试通过；最终CI必须重跑。源码同步ESP32配套PR#250并采用仓库clang-format18规则，不维护公开分叉实现。
    文档：更新中英文合同、验收记录和合并前审查，明确已有HIL镜像与最终补充代码的证据边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
2026-10-07 fix(display): 同步主线 DMA 生命周期并补齐跨平台回收回归
    与 ESP32#250 合并最新开发主线保持一致，保留显示持有型 staging 与安全关闭。排空SPI和解绑ISR失败不释放缓冲，所有退出路径解锁并可重试。公共CI新增实际生产函数的LCD staging/release主机测试，不复制运行时实现。
    验证：Windows Debug/Release新增4次CTest通过，63项工具测试通过；最终提交重新跑三个IDF示例及Windows/Linux主机CI。文档与验收/审查证据同步，旧HIL不冒充本次最终源代码的完整硬件验收。
2026-10-07 style(display): 保持公开头文件与开发源 CI 格式一致
    同步ESP32配套PR#250使用clang-format18.1.3的LVGL默认配置宏布局，仅调整续行格式，不改变参数、默认值和ABI。公开SDK仍是开发源交付快照。
2026-10-14 docs(readme): 增加中英文京东整机预购入口
    在项目简介后、预览图前增加获取机器人小节，突出京东预购链接，方便希望直接体验整机的用户跳转。
    同步说明海外购买渠道即将上线，并保留自行组装的快速开始入口。
    移除京东链接中的追踪参数，保留商品 ID；预购规则与预计发货时间以商品页为准。
    新增开发档案，记录需求、方案、范围与验证依据。
    验证：中英文商品链接、标题锚点及插入位置核对通过；git diff --check 通过。
    本次仅涉及文档，不适用运行时代码 TDD，不包含 SDK 开发改动。
2026-10-15 feat(wiki): 整合公开仓库文档站并建立正式版本自动更新链路
    以原始双语 Markdown 为唯一正文来源，迁入现有主题与客户端补充指南，构建时转换导航、图片、PDF 和源码链接，保留原文 GitHub 阅读方式。
    增加正式 Release 构建附件流程及无凭据拉取更新器，校验归档与版本身份后原子切换，健康检查失败回滚。提供双平台入口、systemd 定时器、Nginx 样例及维护说明。
    验证：6 项 Node 测试及 48 页生产构建通过；真实 Linux 上 7 项更新/回滚测试通过；Windows 明确跳过 4 项符号链接用例。未混入其他 checkout 的硬件 SDK 工作。
2026-10-15 docs(wiki): 补充生产部署与自动更新验证档案
    记录整合站点的 HTTPS 路由与浏览器验收、实际构建版本和产物摘要，以及 AWS 定时器安装与缺少附件时保留旧版的执行结果。补充 GitHub 全部检查通过的证据，明确 PR 待合入、真实 Release 发布链路尚待验证，不将首次部署冒充正式版本发布。
2026-10-15 docs(wiki): 完善双语使用、复现与开发指南
2026-10-17 [文档] 添加精简的双语 PCB 制作与 SMT 贴片指引 (#10)
    * docs(pcb): 添加精简的双语制作与贴片指引
    * docs(pcb): 裁剪截图中的浏览器书签栏
    ---------
2026-10-17 feat(wiki): 支持文档图片放大预览 (#11)
2026-10-28 docs(wiki): 隐藏三项开发预览导航
2026-10-29 docs(wiki): 添加整机拼装教程
2026-10-29 docs(wiki): 对齐拼装教程最终结构
2026-10-29 fix(wiki): 使用同源拼装视频地址 (#13)
2026-10-30 sdk: 同步 watcher_hw 公开开发预览、双语指南与测试闭环 (#14)
    * feat(sdk): 固定导出 watcher_hw 硬件快照与四个独立示例
    从 ab4e324e2b15a1be5431c34de106f05d55ccb99e 显式白名单导出 428 文件并记录逐文件哈希；排除私有 privacy、test_apps 与归档。保留并适配公开 LCD 回归，删除旧 namespace 与过期依赖锁；公开 IDF 新构建由后续任务完成。
    * docs(sdk): 完成双语安全指南、Wiki 分区及预览 CI 验证闭环
    明确 SERIAL-B、Python 3.10+ 下载包、应用不能从 0x0 网页烧录及 agentcfg 覆盖与完整恢复要求。记录待发布预览入口、实际 Python/Node/host/LVGL 结果与 SSCMA 缺依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
2026-11-03 docs: 重整 Wiki 首页、精简导航与社区入口并更新拼装 GIF (#15)
    * docs(wiki): 使用 GIF 展示拼装部件
    * docs(wiki): consolidate resource indexes and support entry points
    * docs(community): add Discord alongside existing WeChat entry
    * style(community): place WeChat and Discord in side-by-side cards
    * docs(wiki): introduce product and lead capabilities with feature overview
    * docs(wiki): restructure homepage and remove redundant capability preambles
2026-11-04 feat(wiki): 统一 ORULINK 品牌导航与黑白文档风格 (#16)
    * feat(wiki): link ORULINK brand logo to the website
    * style(wiki): align documentation with ORULINK monochrome identity
    * style(wiki): use lighter regular headings without synthetic bold
2026-11-05 docs(wiki): 推荐通过 AI Agent Skill 快速创建机器人应用 (#17)
    * docs(wiki): add Skill-led AI application guide and complete download
    * fix(wiki): include original Skill archive in preview source
    * docs(wiki): simplify Skill onboarding and add interactive requirements
    * docs(wiki): make Skill onboarding copy-first and delegate engineering checks
    * fix(wiki): automatically copy prompt on HTTP previews
    * docs(wiki): recommend Skill onboarding across Python entry points
    * fix(wiki): generate deterministic Skill archive during builds
2026-11-13 refactor: C SDK 改用独立子模块，与 Python SDK 并列 (#18)
    * docs: point C SDK users to standalone repository
    * refactor: replace bundled firmware SDK with c-sdk submodule
    * docs: emphasize 2.4 GHz-only Wi-Fi before provisioning
    * docs: keep repository migration details out of user-facing Wiki
